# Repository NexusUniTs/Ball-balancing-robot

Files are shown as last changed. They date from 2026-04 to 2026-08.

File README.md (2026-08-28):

Questo repository contiene la documentazione e i file relativi al progetto del club Nexus Robotics: una piattaforma robotica capace di mantenere in equilibrio una pallina metallica su un piano touch, e di muoverla secondo pattern richiesti, tramite un controllo PID.

> **Stato del progetto**: la progettazione meccanica è conclusa. La programmazione e i test sono ancora in corso.
> 

## Funzionamento

Il robot è composto da un piatto touch resistivo rettangolare, sul quale rotola liberamente una pallina metallica, sostenuto da tre bracci mossi da altrettanti servomotori posti alla base. Il piatto touch rileva in tempo reale la posizione (x, y) della pallina; un Raspberry Pi legge questa posizione e, tramite un algoritmo PID, calcola l'inclinazione da dare al piatto muovendo i tre servomotori (pilotati tramite driver PCA9685), in modo da mantenere la pallina in equilibrio al centro oppure farle seguire un percorso impostato via software.

## Struttura del repository

- **`Progettazione meccanica/`** – File di progettazione Fusion 360 dell'assieme completo (`Assieme.f3z` e `Assieme.stl`), immagine di anteprima (`Assieme.png`)
- **`Programmazione/`** – Codice del controllo PID e gestione servomotori *(in fase di sviluppo)*

## Componenti principali

| **Componente** | **Modello** | **Quantità** |
| --- | --- | --- |
| Micro controllore | Raspberry Pi 4 o 5 | 1 |
| Servomotori | Servo da almeno 17 kg·cm | 3 |
| Driver servo | Scheda driver PCA9685 | 1 |
| Sensore posizione | Wire resistive touch panel (interfaccia USB) | 1 |
| Snodi | Rod end ball joint | 3 |
| Pallina | Pallina di test da 50g | 5 |
| Alimentatore | Alimentatore 5V (dedicato al driver PCA9685) | 1 |
| Varie | Cavi, viti M3 | vari |

*Costi stimati indicativamente; per note aggiuntive sull'alimentazione vedi la documentazione completa.*

## Documentazione completa

Per il dettaglio su progettazione meccanica, assemblaggio, software e attivazione, consulta la documentazione disponibile nella home page del repository.

## Licenza

Vedi il file `LICENSE` nella home page del repository.

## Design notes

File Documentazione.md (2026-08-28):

Progetto Nexus Robotics

> **Stato del progetto**: la progettazione meccanica è conclusa. La programmazione e i test sono ancora in corso — alcune sezioni di questa documentazione saranno completate progressivamente.
> 

---

## 1. Descrizione del progetto

Piattaforma robotica di bilanciamento: tre bracci, mossi da altrettanti servomotori posti alla base, muovono un piatto su cui è montato un pannello touch resistivo rettangolare. Su questo piatto si muove una pallina metallica. Un Raspberry Pi legge la posizione della pallina dal touch panel e, tramite un controllo PID, pilota i servomotori per mantenere la pallina in equilibrio al centro del piatto, oppure per farla muovere secondo pattern richiesti.

## 2. Funzionamento

1. Il touch panel resistivo rileva la posizione (x, y) della pallina sul piatto.
2. Il Raspberry Pi legge questa posizione via USB.
3. L'algoritmo PID calcola, in base alla posizione letta (e all'eventuale posizione/pattern target), l'inclinazione da dare al piatto.
4. Il Raspberry Pi invia i comandi ai tre servomotori tramite il driver PCA9685.
5. I tre bracci, collegati al piatto tramite snodi (rod end ball joint), inclinano il piatto di conseguenza.
6. Il ciclo si ripete in continuo, correggendo la posizione della pallina in tempo reale.

## 3. Componenti

| **Componente** | **Modello** | **Quantità** | **Fornitore/Link** | **Costo per unità** |
| --- | --- | --- | --- | --- |
| Micro controllore | Raspberry Pi 5 | 1 | prestato da Asperastra | 0 |
| Servomotori | Servo da almeno 6 kg·cm (scelti da 17 kg·cm) | 3 | Amazon | €12  |
| Driver servo | Scheda driver PCA9685 | 1 | Amazon | €8 |
| Sensore posizione | Wire resistive touch panel (interfaccia USB) | 1 | Amazon | €20 |
| Snodi | Rod end ball joint | 3 | Amazon | €2 |
| Pallina | Pallina di test da 50g | 5 | Amazon | €1 |
| Alimentatore | Alimentatore USB-C (Raspberry Pi) | 1 | Amazon | €10 |
| Alimentatore | Alimentatore 5V dedicato (driver PCA9685) | 1 | Amazon | €10 |
| Varie | Cavi, viti M3 | vari | Amazon | €5 |

**Costo totale stimato del progetto: €100** 

> *Nota: i costi sono stime indicative basate su prodotti equivalenti reperibili su Amazon; possono variare in base al venditore.*
> 

> **Attenzione:** Il Raspberry Pi e il driver PCA9685 richiedono alimentazioni separate: un alimentatore USB-C dedicato al Raspberry Pi, e un alimentatore 5V dedicato al driver/servomotori. Verificare sempre il voltaggio corretto prima di collegare l'alimentazione.
> 

## 4. Schema elettronico
schema_illustrativo_rpi5_servo
## 5. Progettazione meccanica

Tutte le parti sono state progettate in Fusion 360 e sono disponibili nella cartella `Progettazione meccanica/`:

- **`Assieme.f3z`**/`Assieme.stl` – progetto Fusion 360 dell'assieme completo. Aprendo questo file è possibile visualizzare e modificare ogni singolo componente del modello.
- **`Assieme.png`** – immagine di anteprima dell'assieme.

Tutti i componenti (base, bracci, supporto del piatto) sono stampati in PLA. Il piatto touch è fissato tramite clip stampate in 3D.

## 6. Assemblaggio

Montaggio manuale con viti M3:

- Fissaggio dei tre servomotori alla base
- Fissaggio della base e dell'elettronica (Raspberry Pi, driver PCA9685)
- Collegamento dei bracci al piatto tramite i rod end ball joint
- Il piatto touch viene bloccato in posizione tramite clip stampate in 3D (nessuna vite necessaria per il fissaggio del touch panel)

## 7. Calibrazione

*[Da completare]*

## 8. Software

Il codice è scritto in Python, e l’ultima versione è disponibile nella cartella `Programmazione/`.

### Setup del progetto

*[Da completare, incluso il setup del touch panel resistivo]*

### Regolazione del comportamento (PID)

Nel codice sarà possibile modificare i coefficienti del controllo PID per cambiare il comportamento del robot (es. velocità di correzione, stabilità). Si consiglia di modificare un coefficiente alla volta e testare il comportamento prima di procedere con la modifica successiva.

### Interfaccia utente

*[Da completare]*

## 9. Attivazione

1. Assemblare completamente il robot, se non già fatto (vedi sezione 6).
2. Controllare che i servomotori siano collegati correttamente al driver PCA9685, seguendo lo schema elettronico (vedi sezione 4).
3. Accendere il Raspberry Pi.
4. Verificare il setup del touch panel *(sezione da completare — vedi sezione 8)*.
5. Avviare il codice *[nome dello script da definire]*.

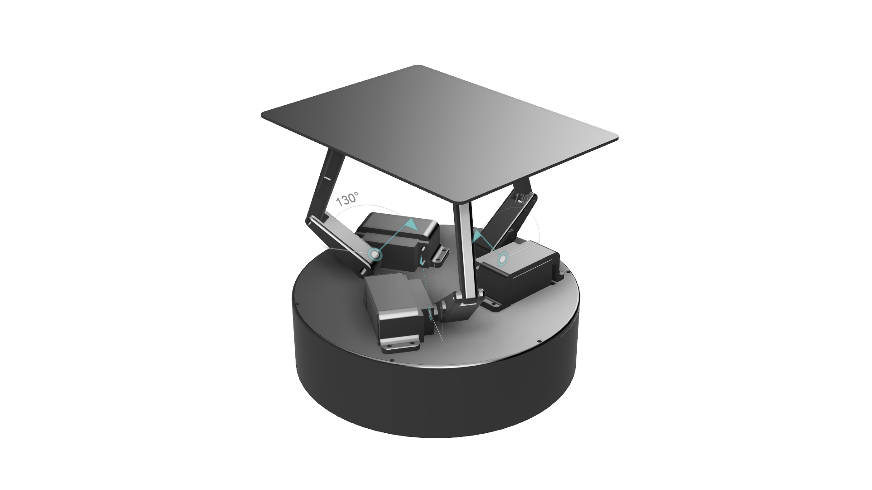
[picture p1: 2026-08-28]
Progettazione meccanica/Assieme.png

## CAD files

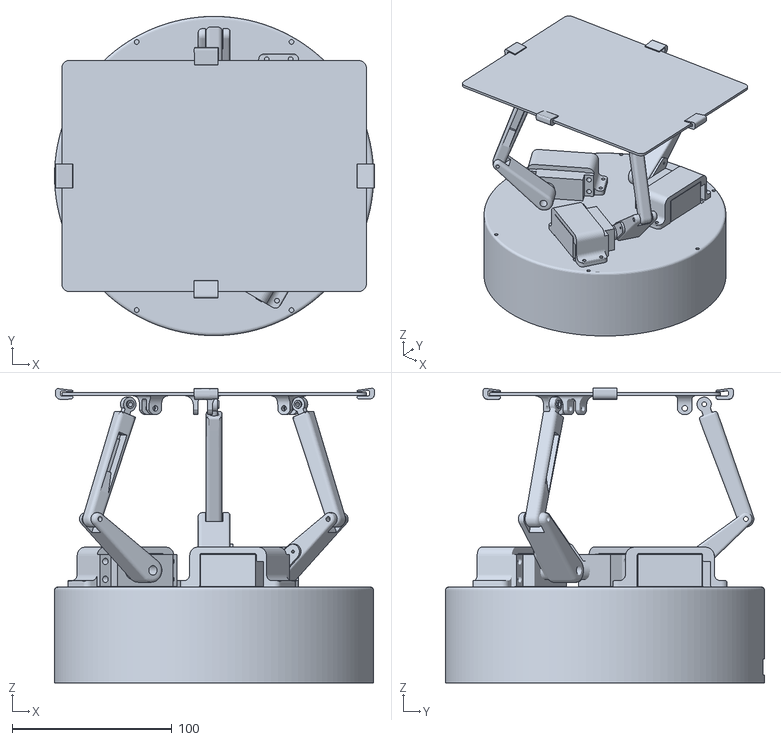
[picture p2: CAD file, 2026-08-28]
Progettazione meccanica/Assieme.stl
200.5 x 200.0 x 184.6

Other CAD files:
Progettazione meccanica/Assieme.f3z

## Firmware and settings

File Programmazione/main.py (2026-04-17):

"""
Ball and Beam 3-DOF Controller (Stewart Platform)
-------------------------------------------------
Questo script implementa un controller PID per bilanciare una pallina
su un pannello touchscreen resistivo mosso da tre servomotori.

Hardware richiesto:
- Raspberry Pi
- Controller PWM PCA9685 (connesso via I2C)
- 3x Servomotori (collegati ai canali 0, 1, 2 del PCA9685)
- Touchscreen resistivo USB (letto tramite subsystem evdev di Linux)

Dipendenze:
- adafruit-circuitpython-pca9685
- adafruit-circuitpython-motor
- evdev
"""

import time
import math
import board
import busio
from adafruit_pca9685 import PCA9685
from adafruit_motor import servo
from evdev import InputDevice, ecodes

# ==============================================================================
# 1. CONFIGURAZIONE HARDWARE E MECCANICA
# ==============================================================================

# -- Configurazione Touchscreen --

# COME TROVARE IL PERCORSO DEL TOUCHSCREEN (DEVICE PATH):
# 1. Apri il terminale del Raspberry Pi.
# 2. Esegui il comando: sudo python3 -m evdev.evtest
# 3. Individua nell'elenco stampato a schermo il nome del tuo controller USB 
#    (es. "VSDISPLAY", "USB Touch Controller", ecc.).
# 4. Annota il percorso ad esso associato (es. "/dev/input/event4") e inseriscilo 
#    nella variabile TOUCH_DEVICE qui sotto.
# 
# Nota: se scolleghi e ricolleghi l'USB, il numero dell'evento potrebbe cambiare.
# Per un setup permanente, puoi usare i symlink fissi generati dal sistema, 
# verificando il contenuto della cartella: ls -l /dev/input/by-id/

TOUCH_DEVICE = '/dev/input/event4'

# Dimensioni fisiche dell'area sensibile dello schermo (in millimetri)
TOUCH_DIM_X_MM = 140.0
TOUCH_DIM_Y_MM = 180.0

# Valori raw centrali e massimi (da calibrare leggendo l'output raw del sensore)
TOUCH_CENTER_RAW_X = 1980
TOUCH_CENTER_RAW_Y = 1850
TOUCH_MAX_RAW_X = 3960
TOUCH_MAX_RAW_Y = 3700

# -- Configurazione Cinematica (in millimetri) --
KIN_H = 100.0  # Altezza del piatto a riposo (dalla base al centro dello snodo)
KIN_E = 50.0   # Raggio del piatto (distanza centro piatto - snodi delle aste)
KIN_F = 30.0   # Lunghezza della squadretta del servomotore
KIN_G = 80.0   # Lunghezza dell'asta di collegamento (pushrod)

# -- Configurazione PID --
# L'asse X (guidato da 1 motore) e l'asse Y (guidato da 2 motori) hanno inerzie
# differenti. Il tuning deve essere gestito separatamente per evitare overshooting.
PID_X_KP = 0.08
PID_X_KI = 0.0
PID_X_KD = 0.15

PID_Y_KP = 0.15
PID_Y_KI = 0.0
PID_Y_KD = 0.10

PID_OUTPUT_LIMIT_DEG = 12.0  # Limite di sicurezza inclinazione (gradi)

# ==============================================================================
# GUIDA ALLA RISOLUZIONE DEI PROBLEMI DI ORIENTAMENTO
# ==============================================================================
# Se l'hardware non risponde in modo geometricamente coerente, verificare:
#
# 1. ASSI SCAMBIATI (Il robot si inclina di lato quando la pallina va in avanti)
#    Causa: Il sensore touchscreen è ruotato di 90 gradi rispetto ai motori.
#    Soluzione: Nella classe TouchScreenEvdev, metodo leggi_posizione(), 
#    invertire i valori di ritorno (es. "return y_mm, x_mm" invece di "x, y").
#
# 2. ASSE INVERTITO (Il robot si inclina sull'asse giusto, ma nel verso opposto)
#    Causa: Motori o sensori sono montati in modo speculare alla cinematica.
#    Soluzione: Nel loop while principale, invertire il segno della variabile 
#    assegnata a quell'asse (es. current_y = -current_y) prima di passarla al PID.
# ==============================================================================

class TouchScreenEvdev:
    def __init__(self, device_path):
        self.dev = InputDevice(device_path)
        self.dev.grab() # Acquisizione esclusiva per inibire il puntatore di sistema
        
        self.centro_x_raw = TOUCH_CENTER_RAW_X
        self.centro_y_raw = TOUCH_CENTER_RAW_Y
        
        self.scala_x = TOUCH_DIM_X_MM / TOUCH_MAX_RAW_X
        self.scala_y = TOUCH_DIM_Y_MM / TOUCH_MAX_RAW_Y
        
        self.last_x_raw = self.centro_x_raw
        self.last_y_raw = self.centro_y_raw

    def leggi_posizione(self):
        try:
            # Polling degli eventi in modalità non bloccante
            for event in self.dev.read():
                if event.type == ecodes.EV_ABS:
                    if event.code == ecodes.ABS_X:
                        self.last_x_raw = event.value
                    elif event.code == ecodes.ABS_Y:
                        self.last_y_raw = event.value
        except BlockingIOError:
            pass 

        # Traslazione valori raw in coordinate millimetriche assolute
        x_mm = (self.last_x_raw - self.centro_x_raw) * self.scala_x
        y_mm = (self.last_y_raw - self.centro_y_raw) * self.scala_y
        
        # Scambio assi software applicato per conformità con la geometria attuale.
        # Ripristinare 'return x_mm, y_mm' in caso di montaggio standard allineato.
        return y_mm, x_mm
        
    def rilascia(self):
        self.dev.ungrab()

class PID:
    def __init__(self, kp, ki, kd, limite_output):
        self.kp = kp
        self.ki = ki
        self.kd = kd
        self.limite_output = limite_output
        self.prev_error = 0.0
        self.integral = 0.0
        self.prev_time = time.time()

    def update(self, setpoint, current_value):
        current_time = time.time()
        dt = current_time - self.prev_time
        if dt <= 0.0: 
            dt = 1e-4

        error = setpoint - current_value
        
        self.integral += error * dt
        # Limite Anti-windup sull'integrale per evitare instabilità a lungo termine
        self.integral = max(-50.0, min(50.0, self.integral)) 
        
        derivative = (error - self.prev_error) / dt
        output = (self.kp * error) + (self.ki * self.integral) + (self.kd * derivative)
        
        self.prev_error = error
        self.prev_time = current_time
        
        return max(-self.limite_output, min(self.limite_output, output))

# ==============================================================================
# CINEMATICA (Stewart Platform)
# ==============================================================================

COS_30 = math.cos(math.radians(30))
SIN_30 = math.sin(math.radians(30))

def calcola_altezze_vertici(pitch_deg, roll_deg):
    theta = math.radians(pitch_deg)
    phi = math.radians(roll_deg)
    
    zA = KIN_H + (KIN_E * math.sin(theta))
    zB = KIN_H + (KIN_E * COS_30 * math.sin(phi)) - (KIN_E * SIN_30 * math.sin(theta))
    zC = KIN_H - (KIN_E * COS_30 * math.sin(phi)) - (KIN_E * SIN_30 * math.sin(theta))
    return zA, zB, zC

def calcola_angolo_servo(zi):
    Li = zi
    try:
        parte1 = math.asin(zi / Li)
        argomento_arccos = max(-1.0, min(1.0, (KIN_F**2 + Li**2 - KIN_G**2) / (2 * KIN_F * Li)))
        parte2 = math.acos(argomento_arccos)
        
        angolo_out = math.degrees(parte1 + parte2)
        return max(0.0, min(180.0, angolo_out))
    except ValueError:
        return 90.0

# ==============================================================================
# MAIN LOOP
# ==============================================================================

def main():
    print("[INFO] Inizializzazione bus I2C e controller PCA9685...")
    i2c = busio.I2C(board.SCL, board.SDA)
    pca = PCA9685(i2c)
    pca.frequency = 50
    
    # Assegnazione motori ai rispettivi canali I2C sulla shield
    motore_A = servo.Servo(pca.channels[0], min_pulse=500, max_pulse=2500)
    motore_B = servo.Servo(pca.channels[1], min_pulse=500, max_pulse=2500)
    motore_C = servo.Servo(pca.channels[2], min_pulse=500, max_pulse=2500)

    print(f"[INFO] Inizializzazione Touchscreen su {TOUCH_DEVICE}...")
    touch = TouchScreenEvdev(TOUCH_DEVICE)

    print("[INFO] Esecuzione homing motori (90 gradi)...")
    motore_A.angle = 90
    motore_B.angle = 90
    motore_C.angle = 90
    time.sleep(1.5)

    pid_pitch = PID(PID_X_KP, PID_X_KI, PID_X_KD, PID_OUTPUT_LIMIT_DEG)
    pid_roll  = PID(PID_Y_KP, PID_Y_KI, PID_Y_KD, PID_OUTPUT_LIMIT_DEG)
    
    setpoint_x, setpoint_y = 0.0, 0.0

    print("[INFO] Sistema avviato. Control loop in esecuzione.")

    try:
        while True:
            # 1. Acquisizione Sensore
            current_x, current_y = touch.leggi_posizione()

            # --- CORREZIONE ORIENTAMENTO FISICO ---
            # Fare riferimento alla guida a inizio script in caso di discrepanze.
            current_y = -current_y 
            
            # De-commentare la riga seguente se anche l'asse X spinge nel verso opposto:
            # current_x = -current_x

            # 2. Controllo PID
            pitch_target = pid_pitch.update(setpoint_x, current_x)
            roll_target = pid_roll.update(setpoint_y, current_y)

            # 3. Cinematica Inversa
            zA, zB, zC = calcola_altezze_vertici(pitch_target, roll_target)
            angolo_A = calcola_angolo_servo(zA)
            angolo_B = calcola_angolo_servo(zB)
            angolo_C = calcola_angolo_servo(zC)

            # 4. Attuazione Fisica
            motore_A.angle = angolo_A
            motore_B.angle = angolo_B
            motore_C.angle = angolo_C
            
            # Telemetria standard output
            print(f"X:{current_x:6.1f} Y:{current_y:6.1f} | PID_P:{pitch_target:5.1f} PID_R:{roll_target:5.1f} | M_A:{angolo_A:5.1f}")

            # Mantenimento frequenza loop target (~50Hz)
            time.sleep(0.02) 

    except KeyboardInterrupt:
        print("\n[WARN] Interruzione manuale (SIGINT) rilevata. Arresto del sistema.")
        motore_A.angle = 90
        motore_B.angle = 90
        motore_C.angle = 90
        time.sleep(0.5)
    finally:
        pca.deinit()
        touch.rilascia()
        print("[INFO] Terminazione completata. Risorse hardware rilasciate.")

if __name__ == "__main__":
    main()

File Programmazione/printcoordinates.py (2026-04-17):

from evdev import InputDevice, ecodes

# Cambia 'event0' con il numero del tuo dispositivo!
dev = InputDevice('/dev/input/event0')

# Prende il controllo esclusivo cosÃ¬ non muovi il mouse di sistema
dev.grab()

print(f"Pronto! Sto ascoltando le coordinate su: {dev.name}")
print("Tocca lo schermo. Premi Ctrl+C per uscire.")

# Variabili per memorizzare l'ultima posizione letta
x = 0
y = 0

try:
    for event in dev.read_loop():
        # Filtriamo solo gli eventi di tipo "movimento assoluto" (touchscreen)
        if event.type == ecodes.EV_ABS:
            
            if event.code == ecodes.ABS_X:
                x = event.value
                print(f"Coordinate -> X: {x} | Y: {y}")
                
            elif event.code == ecodes.ABS_Y:
                y = event.value
                print(f"Coordinate -> X: {x} | Y: {y}")

except KeyboardInterrupt:
    # Rilascia il dispositivo quando premiamo Ctrl+C
    dev.ungrab()
    print("\nTest terminato. Dispositivo rilasciato.")

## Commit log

2026-04-17 Add main PID controller script for ball balancing robot
2026-08-28 Add project documentation for Nexus Robotics
    Added detailed project documentation for Nexus Robotics, including project description, functioning, components, electronic schema, mechanical design, assembly instructions, calibration, software set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
2026-10-10 Possibile soluzione funzionamento MK2
    Caricata la cartella di una possibile soluzione al mal funzionamento del robot. Nella cartella c'è un pdf che riassume la cinematica inversa, il codice per controllare il robot e il codice di control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
2026-10-10 Spostata la cartella test mk2
